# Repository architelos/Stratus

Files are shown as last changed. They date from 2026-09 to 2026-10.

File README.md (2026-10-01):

# Stratus

My take on an custom, open source yet practical drone stack.

## Jett (ESC)

<p align="center">
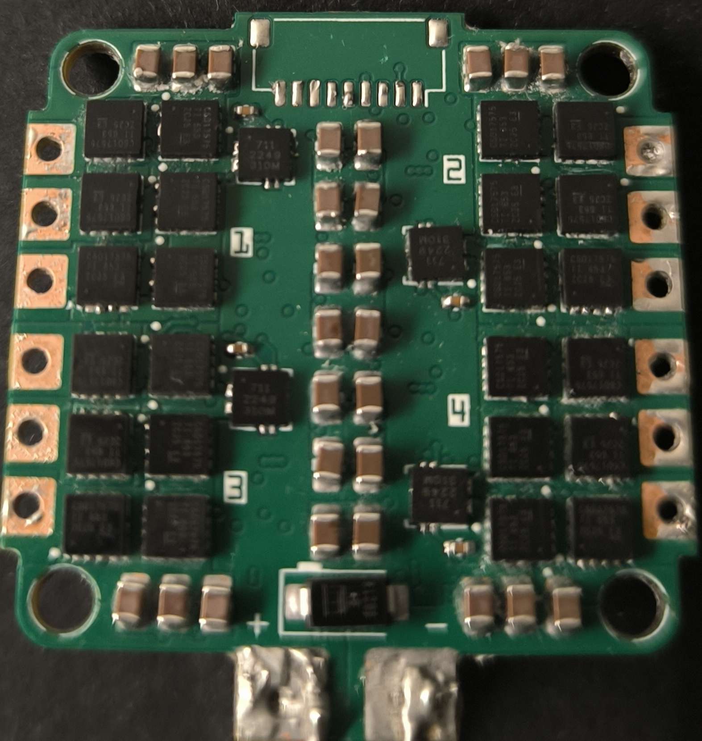
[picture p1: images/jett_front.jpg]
  
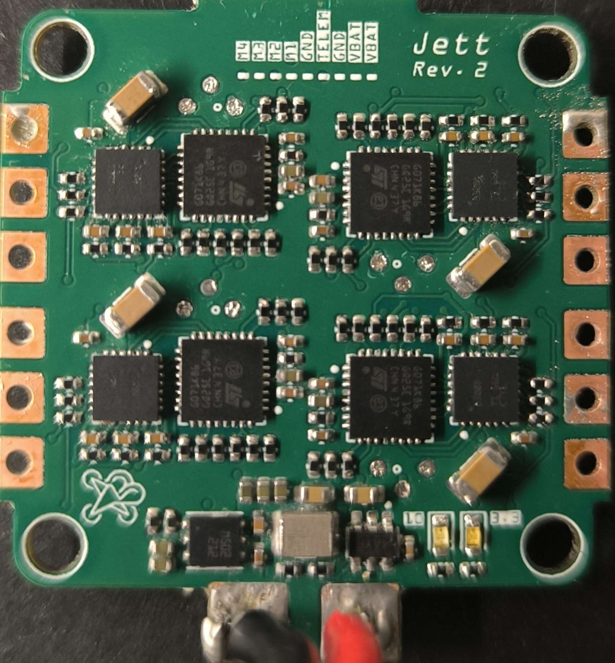
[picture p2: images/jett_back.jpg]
  
</p>

**Current revision:** 2\
**Status:** Testing

### Specs

| | |
| --- | --- |
| MCU | STM32G071K(B/8)U(3/6) |
| Gate driver | DRV8300DRGER |
| PWM | 48 kHz |
| Input | 2S to 4S LiPo |
| Continuous current | 25 A continuous, 30 A peaks |
| Current sensing | High side hall effect sensor |
| Throttle interface | DShot / ... (standard protocols) |
| Telemetry | Serial UART |
| Capacitor bank | 26 × 10 µF 0805 MLCC |
| PCB | 38 x 41.5 mm, 30.5 × 30.5 mm mounting |
| Copper | 2 oz outer, 0.5 oz inner |

### Description

Built from the ground up to understand what is happening inside an ESC, rather than treating it as a black box. Jett uses industry standard AM32, and has hardware designed around being able to inspect, modify, and learn from the system.

**Power tree:** `VBAT → 10V buck (driving FETs) → 3.3V low-noise LDO`

## Kite (FC)

<p align="center">
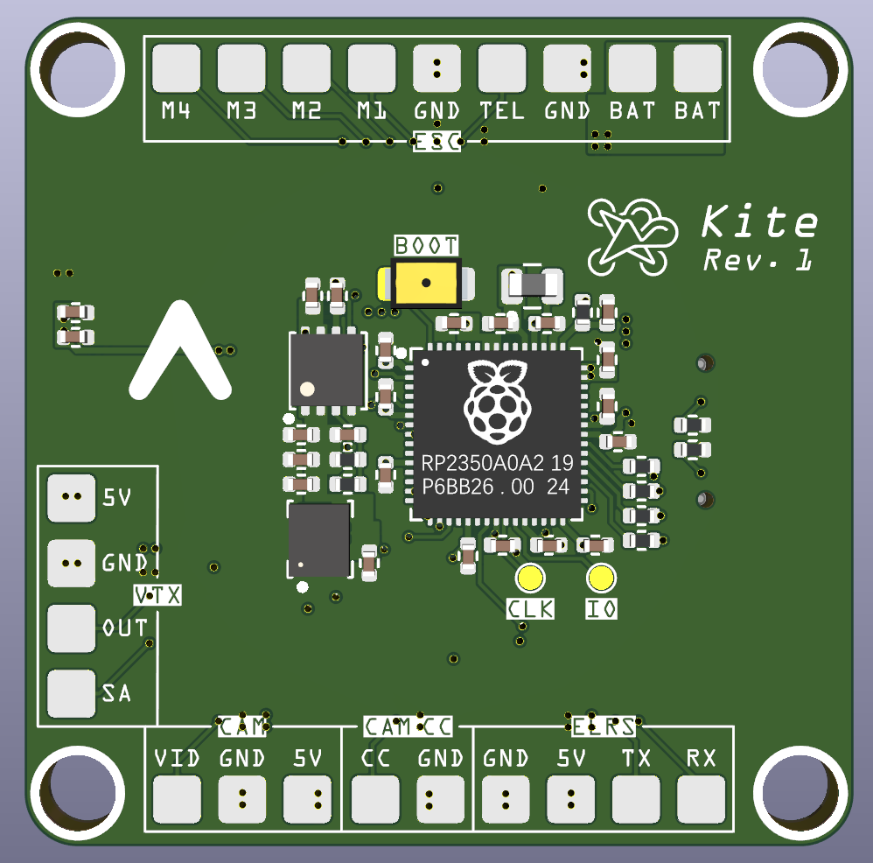
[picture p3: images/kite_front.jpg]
  
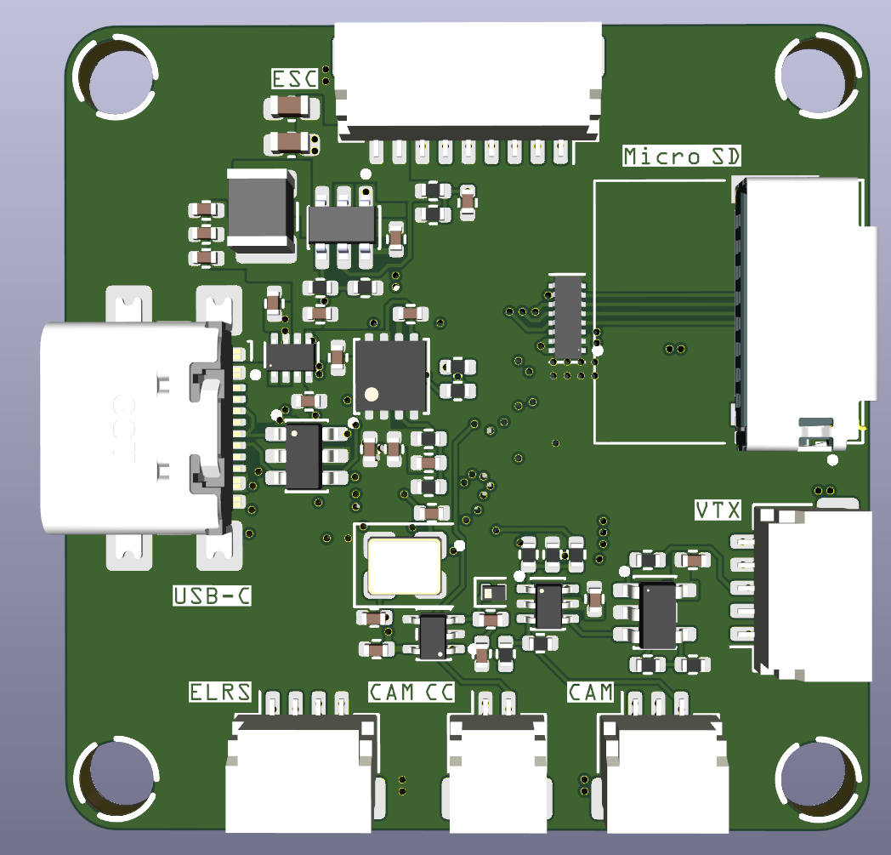
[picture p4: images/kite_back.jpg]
  
</p>

**Current revision:** 1\
**Status:** Waiting

### Specs

| | |
| --- | --- |
| MCU | RP2354A |
| IMU | LSM6DSK320X |
| Input | 2S to 4S LiPo |
| BECs | 5V → VTX + Camera ; 3V3 → MCU + IMU |
| Connectivity | USB-C / JST-SH |
| Storage | MicroSD |
| Firmware | Betaflight |
| PCB | 38 × 38 mm, 30.5 × 30.5 mm mounting |
| Copper | 1 oz outer, 0.5 oz inner |

The flight controller completes the Stratus stack, with the same focus on practical hardware and understanding the underlying system.

## License

CERN-OHL-2.0, see [LICENSE](LICENSE)

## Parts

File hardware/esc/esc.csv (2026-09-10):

Reference | Qty | Value | MFR | MPN | LCSC# | Footprint | Description | DNP | Exclude from Board | Exclude from BOM | Datasheet
C2,C6,C9,C10,C11,C15,C18,C19,C20,C24,C27,C28,C29,C33,C36,C37,C39,C70 | 18 | 0.1uF | TDK | CGA2B3X7R1V104KT0Y0F | C343047 | Stratus:C_0402 | 0402 0.1uF 35V
C3,C12,C21,C30,C40,C42,C65,C68,C69 | 9 | 4.7uF | Taiyo Yuden | TDK105CBJ475MV-F | C22385335 | Stratus:C_0402 | 0402 4.7uF 25V
C4,C5,C8,C13,C14,C17,C22,C23,C26,C31,C32,C35,C43 | 13 | 1uF | Murata | GRM155R6YA105KE11J | C3835721 | Stratus:C_0402 | 0402 1uF 35V
C7,C16,C25,C34 | 4 | 10uF | Samsung | CL31B106KLHNNNE | C16195875 | Capacitor_SMD:C_1206_3216Metric | 1206 10uF 35V
C44,C45,C46,C47,C48,C49,C50,C54,C55,C56,C57,C58,C59,C60,C61,C62,C64,C73,C74,C75,C76,C77,C78,C79,C80,C81 | 26 | 10uF | Murata | GRM21BR6YA106KE43L | C162422 | Capacitor_SMD:C_0805_2012Metric | 0805 10uF 35V
C66,C67 | 2 | 4.7uF | Samsung | CL10A475KL8NRNC | C307467 | Capacitor_SMD:C_0603_1608Metric | 0603 4.7uF 35V
D1,D2 | 2 | Green | Vishay | VLMTG1400-GS08 | C3000897 | LED_SMD:LED_0603_1608Metric | 0603 Green LED
D3 | 1 | SMAJ20A | Littelfuse | SMAJ20A | C148209 | Stratus:SMAJ20A | 32.4VC DO-214AC |  |  |  | https://www.littelfuse.com/media?itemid=75e32973-b177-4ee3-a0ff-cedaf1abdb93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
J1 | 1 | TO_FC | JST | SM09B-SRSS-TB(LF)(SN) | C160408 | Connector_JST:JST_SH_SM09B-SRSS-TB_1x09-1MP_P1.00mm_Horizontal | Horizontal JST-SH 1x9
J4,J7,J10,J13 | 4 | PHASE_A |  |  |  | Stratus:Phase_Pad_3x3_D1.5 | Motor output pad
J5,J8,J11,J14 | 4 | PHASE_B |  |  |  | Stratus:Phase_Pad_3x3_D1.5 | Motor output pad
J6,J9,J12,J15 | 4 | PHASE_C |  |  |  | Stratus:Phase_Pad_3x3_D1.5 | Motor output pad
L1 | 1 | 4.7uH | TDK | BCL322520RT-4R7M-D | C3224690 | Inductor_SMD:L_1210_3225Metric | 1210 4.7uH 2.5A Isat
Q1,Q2,Q3,Q4,Q5,Q6,Q7,Q8,Q9,Q10,Q11,Q12,Q13,Q14,Q15,Q16,Q17,Q18,Q19,Q20,Q21,Q22,Q23,Q24 | 24 | CSD17575Q3 | TI | CSD17575Q3 | C529277 | Stratus:CSD17575Q3 | N-Channel MOSFET 30V 60A 2.8W |  |  |  | https://www.ti.com/lit/ds/symlink/csd17575q3.pdf
R1,R3 | 2 | 1k | Yageo | RC0402FR-071KL | C106235 | Stratus:R_0402 | 0402 1k
R5,R13,R14,R15,R22,R30,R31,R32,R39,R47,R48,R49,R56,R64,R65,R66,R76,R77 | 18 | 10k | Yageo | RC0402FR-0710KL | C60490 | Stratus:R_0402 | 0402 10k
R6,R7,R8,R9,R11,R12,R23,R24,R25,R26,R28,R29,R40,R41,R42,R43,R45,R46,R57,R58,R59,R60,R62,R63 | 24 | 56k | Yageo | RC0402FR-0756KL | C114756 | Stratus:R_0402 | 0402 56k
R16,R17,R18,R19,R20,R21,R33,R34,R35,R36,R37,R38,R50,R51,R52,R53,R54,R55,R67,R68,R69,R70,R71,R72 | 24 | 27R | Yageo | RC0402FR-0727RL | C138021 | Stratus:R_0402 | 0402 27R
R74 | 1 | 18k | Yageo | RC0402FR-0718KL | C138044 | Stratus:R_0402 | 0402 18k
R75 | 1 | 160k | Yageo | RC0402FR-07160KL | C273334 | Stratus:R_0402 | 0402 160k
TP1,TP5,TP9,TP13 | 4 | DBG_nRST |  |  |  | Stratus:Debug_Pad_D1 | 1x1mm pad for flashing
U1,U4,U7,U10 | 4 | DRV8300DRGER | TI | DRV8300DRGER | C3655801 | Stratus:DRV8300DRGER | https://www.lcsc.com/datasheet/C3655801.pdf |  |  |  | https://www.ti.com/lit/gpn/drv8300
U2,U5,U8,U11 | 4 | STM32G071K8U6 | ST | STM32G071K8U6 | C724237 | Stratus:STM32G071K8U6 | https://www.lcsc.com/datasheet/C724237.pdf |  |  |  | https://www.st.com/resource/en/datasheet/stm32g071c8.pdf
U13 | 1 | LMR51420YFDDCR | TI | LMR51420YFDDCR | C7296200 | Stratus:LMR51420YFDDCR | 4.5-V to 36-V, 2-A, Synchronous Buck Converter |  |  |  | ti.com/lit/ds/symlink/lmr51420.pdf
U14 | 1 | LDL212PUR | ST | LDL212PUR | C2969849 | Stratus:LDLPUR212 | 1.18V~17.3V Positive Adjustable DFN-6(3x3) |  |  |  | https://www.lcsc.com/datasheet/C2969849.pdf
U15,U16,U17,U18 | 4 | ACS711xEXLT-31AB | Allegro | ACS711KEXLT-31AB-T | C146412 | Stratus:ACS711KEXLT-31AB-T | ±31A Bidirectional, Hall-Effect Current Sensor, +3.3V supply, 45mV/A, QFN-12 |  |  |  | http://www.allegromicro.com/~/Media/Files/Datasheets/ACS711-Datasheet.ashx

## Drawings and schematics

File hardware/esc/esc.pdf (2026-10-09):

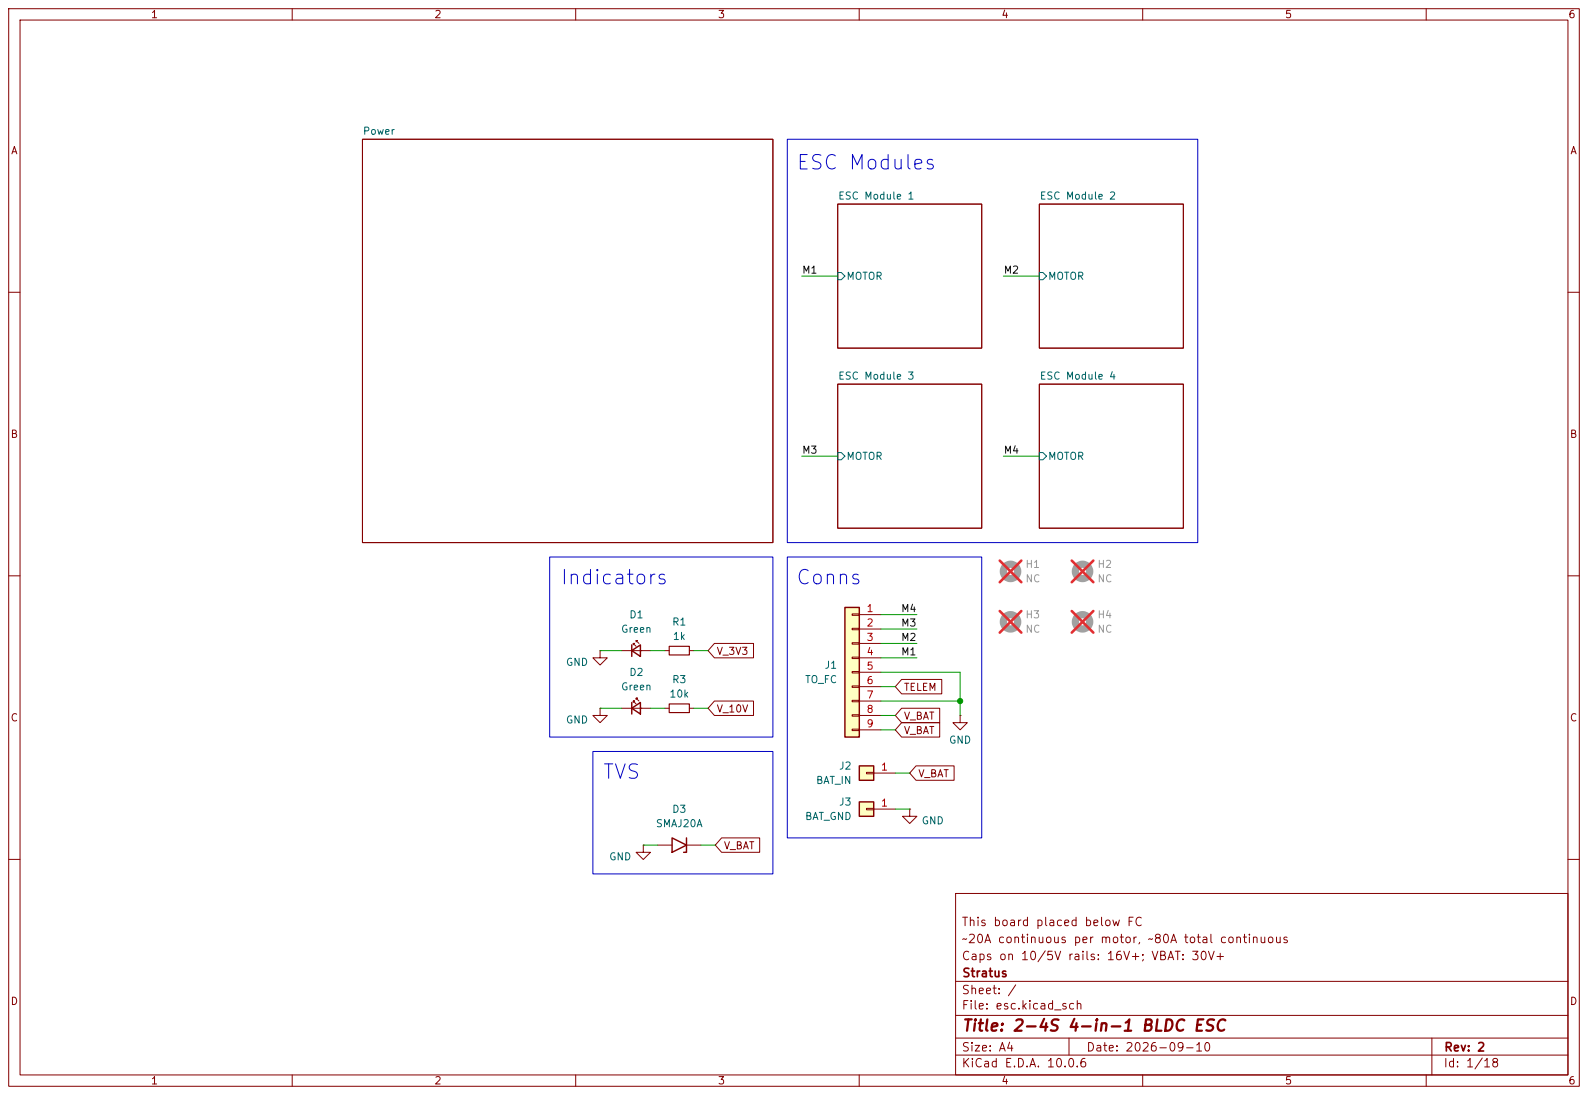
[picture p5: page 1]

This board placed below FC
~20A continuous per motor, ~80A total continuous
Caps on 10/5V rails: 16V+; VBAT: 30V+
Stratus
Sheet: /
File: esc.kicad_sch
Title: 2-4S 4-in-1 BLDC ESC

Size: A4 | Rev: 2
KiCad E.D.A. 10.0.6 | Id: 1/18

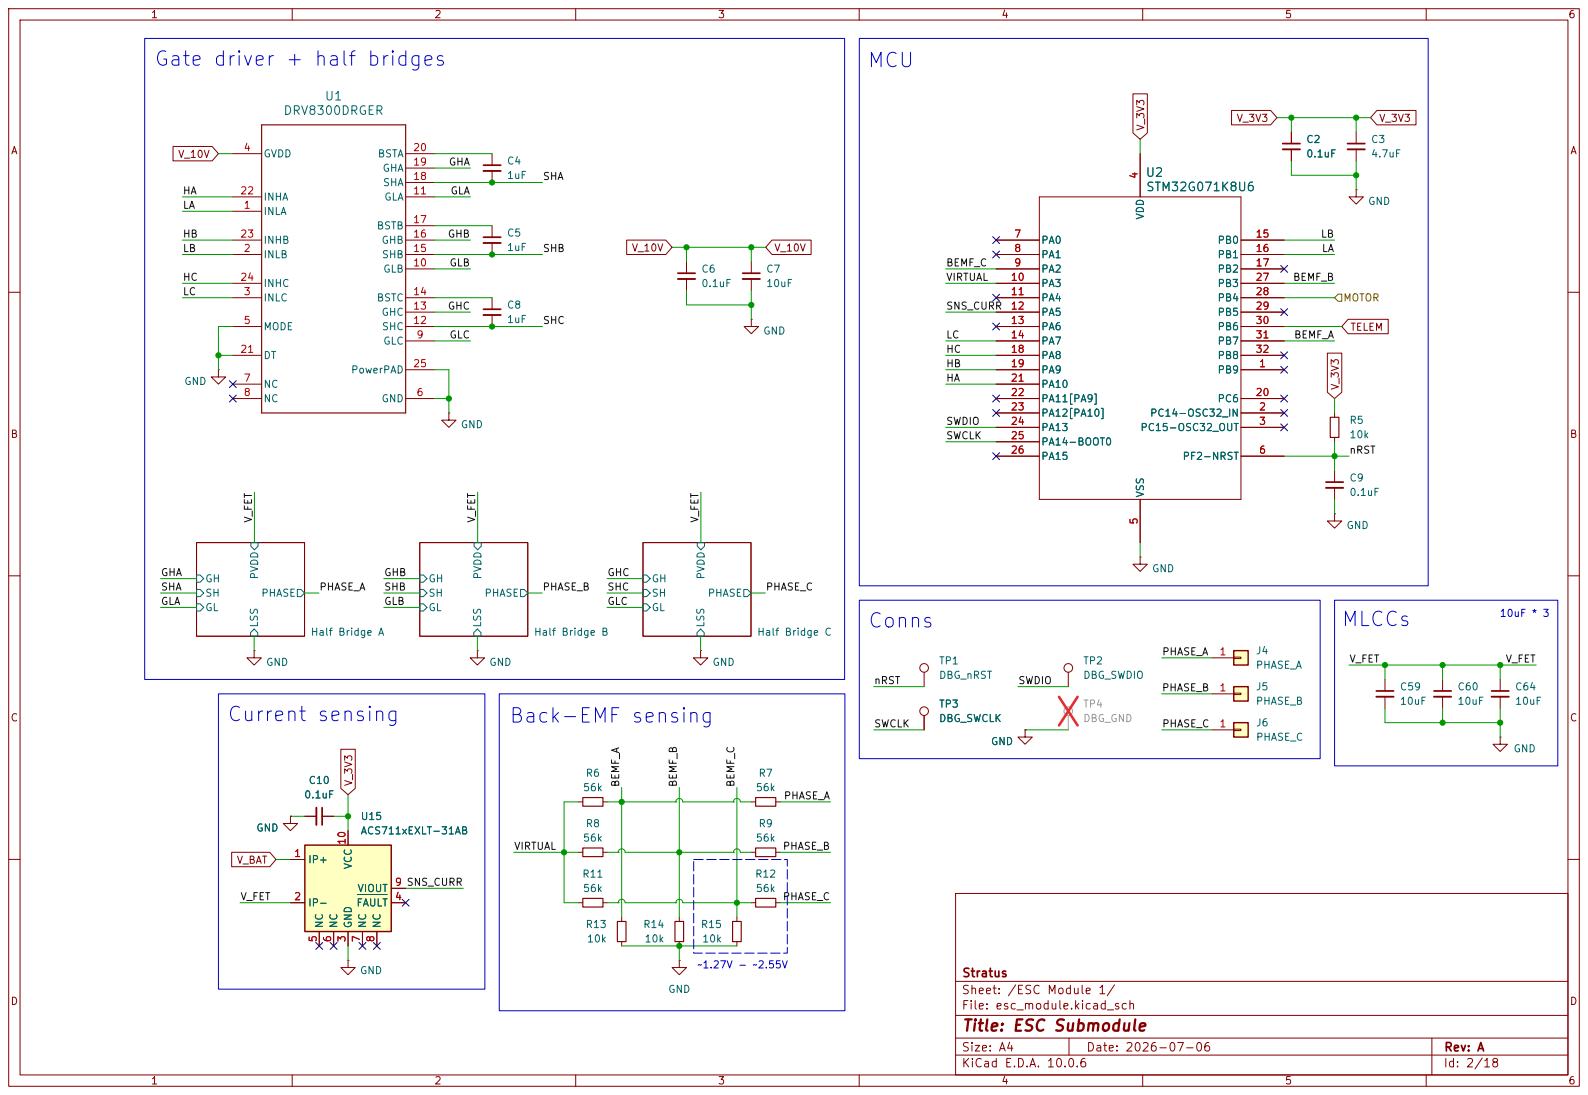
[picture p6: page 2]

~1.27V - ~2.55V Gate driver + half bridges

Stratus LSS PVDD PHASE GH

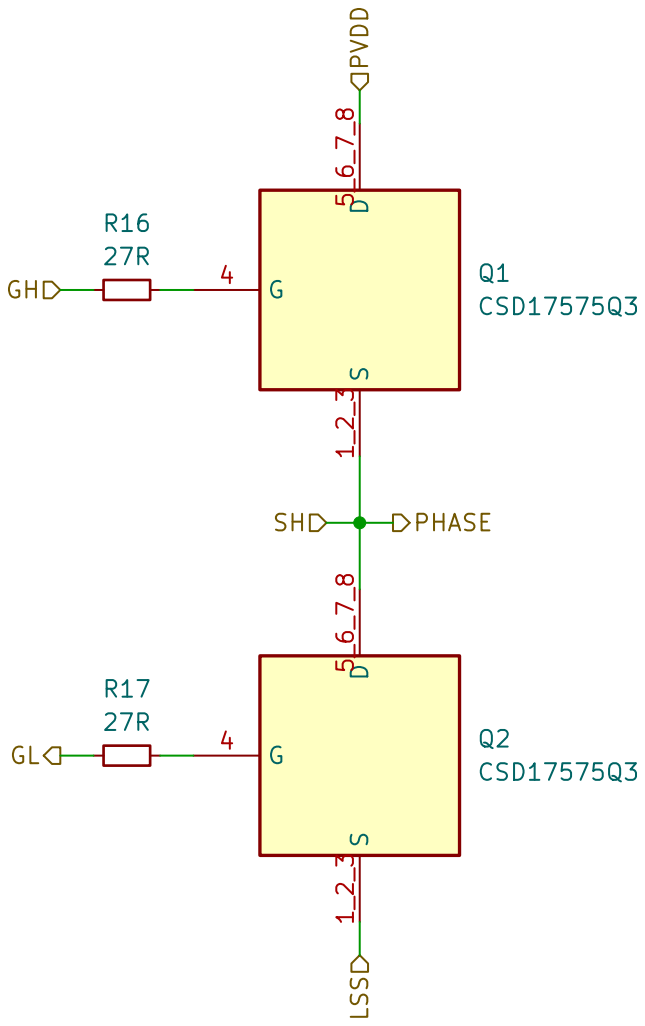
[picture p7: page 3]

Sheet: /ESC Module 1/Half Bridge A/
File: half_bridge.kicad_sch
Title: MOSFET half bridge

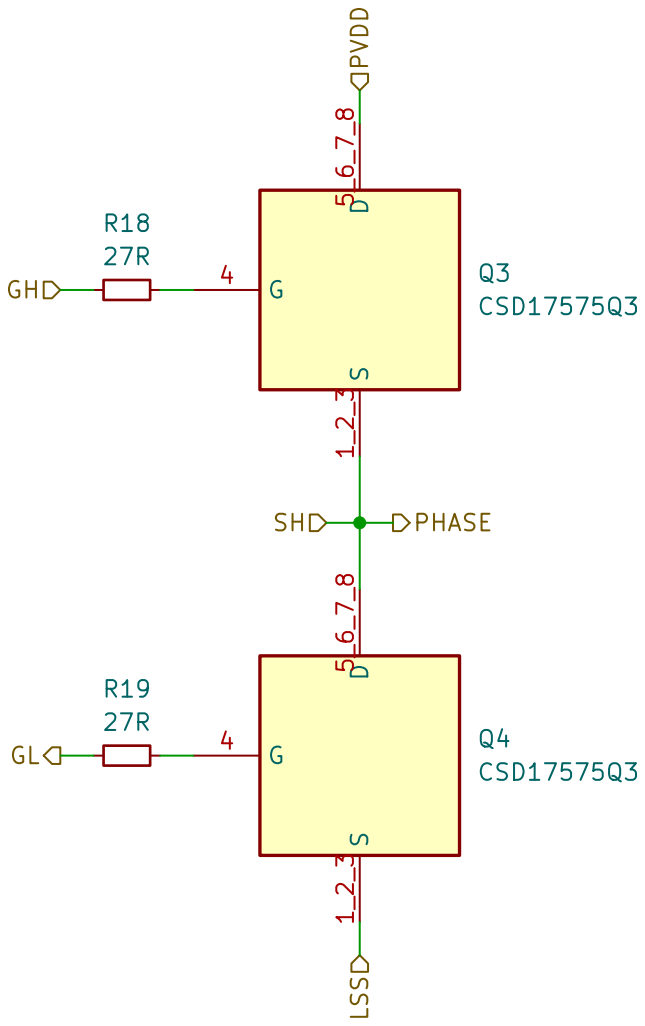
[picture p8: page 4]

Sheet: /ESC Module 1/Half Bridge B/
File: half_bridge.kicad_sch
Title: MOSFET half bridge

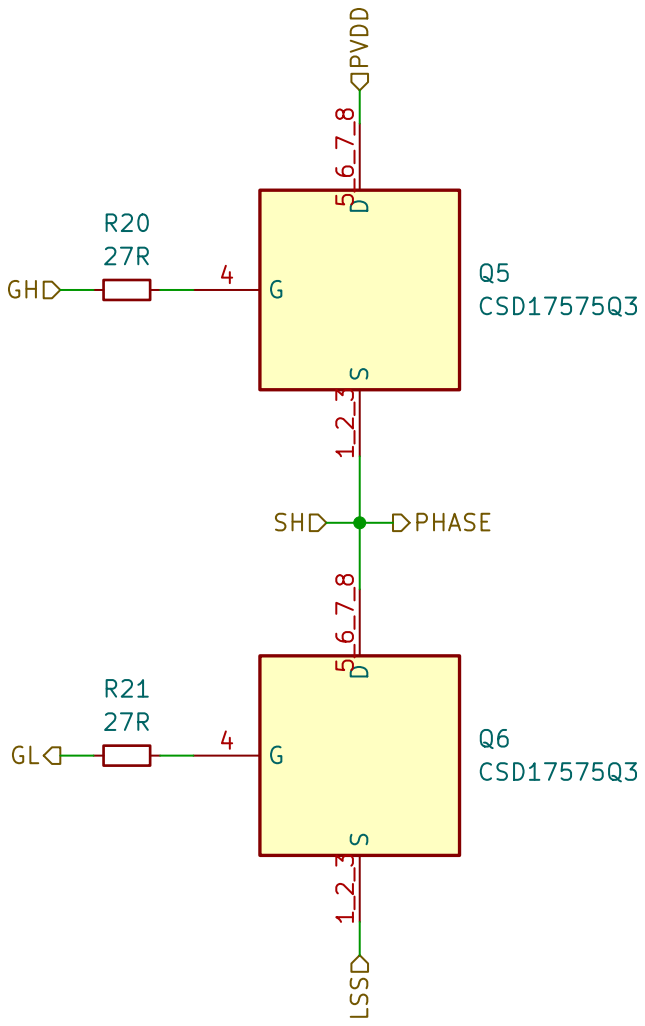
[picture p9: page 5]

Sheet: /ESC Module 1/Half Bridge C/
File: half_bridge.kicad_sch
Title: MOSFET half bridge

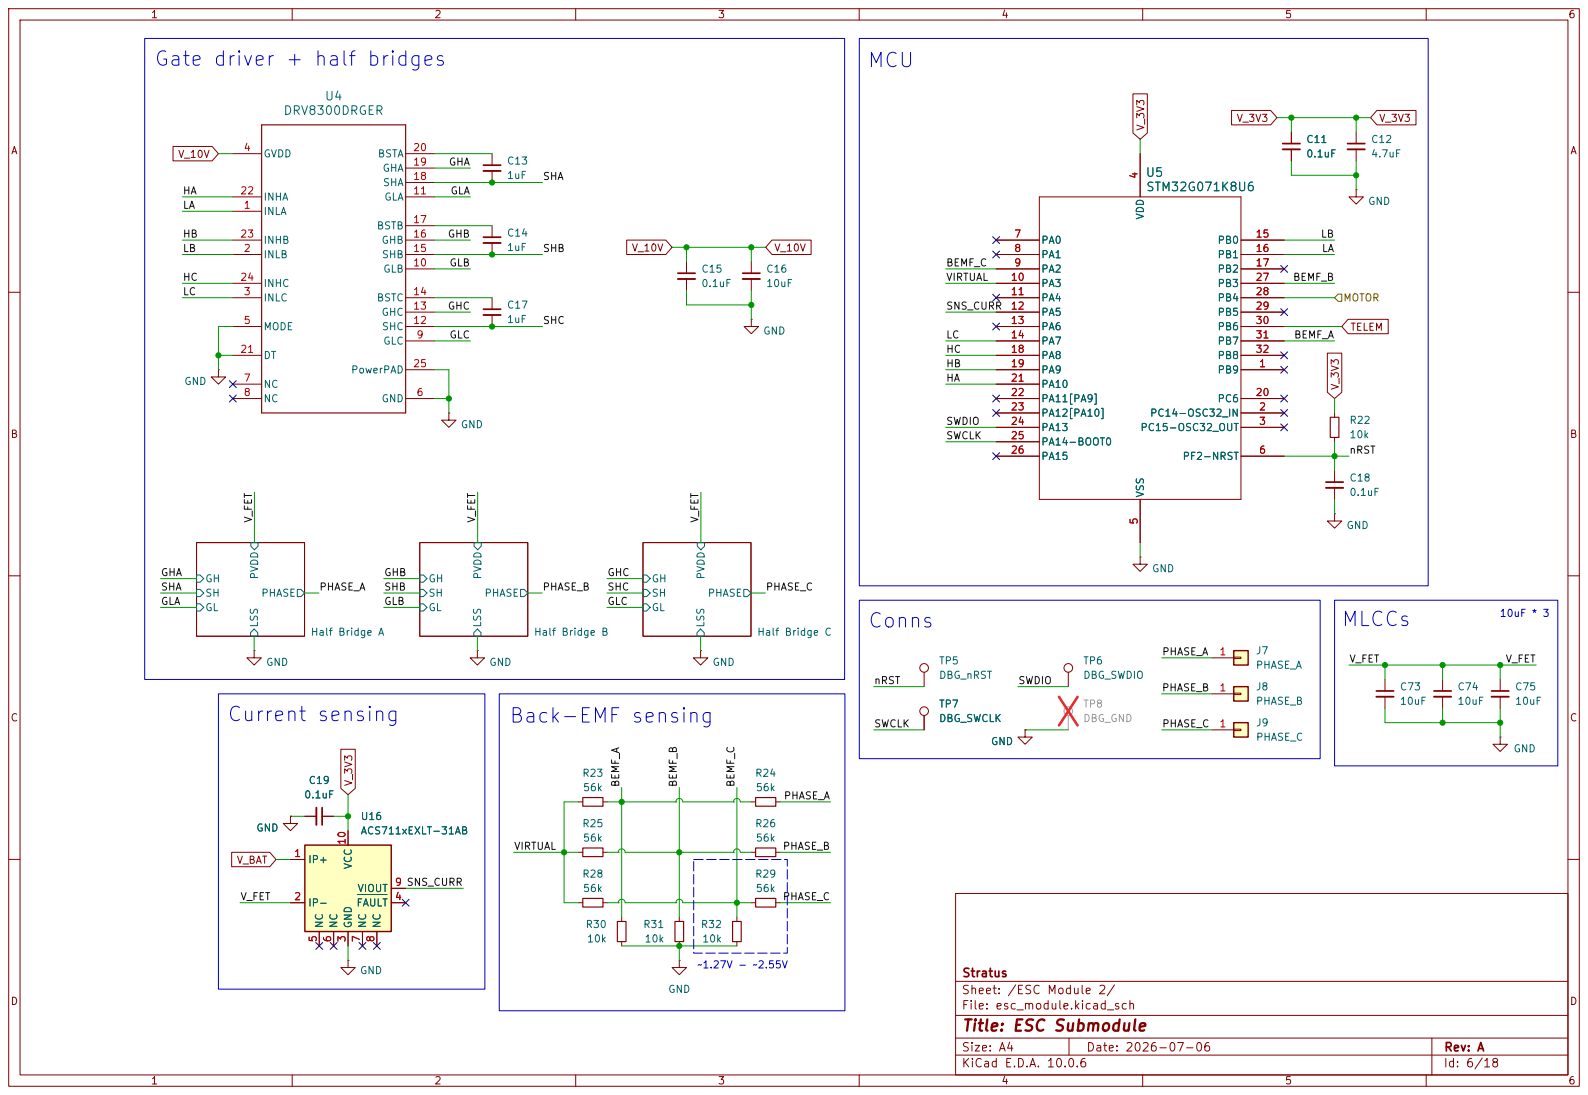
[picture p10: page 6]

10uF * 3 Gate driver + half bridges

Stratus LSS PVDD PHASE GH

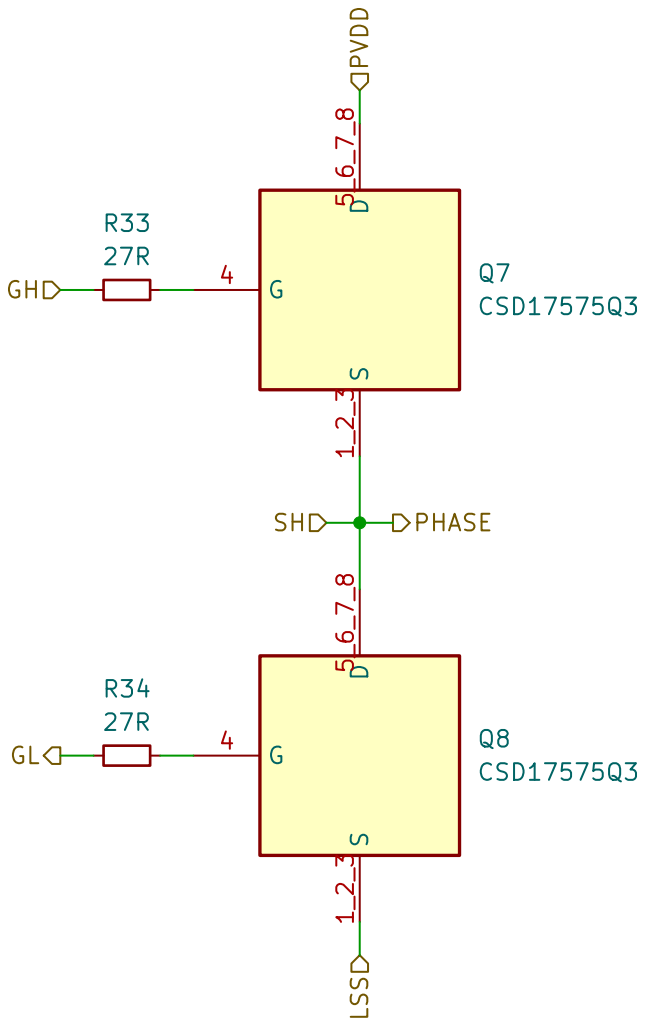
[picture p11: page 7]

Sheet: /ESC Module 2/Half Bridge B/
File: half_bridge.kicad_sch
Title: MOSFET half bridge

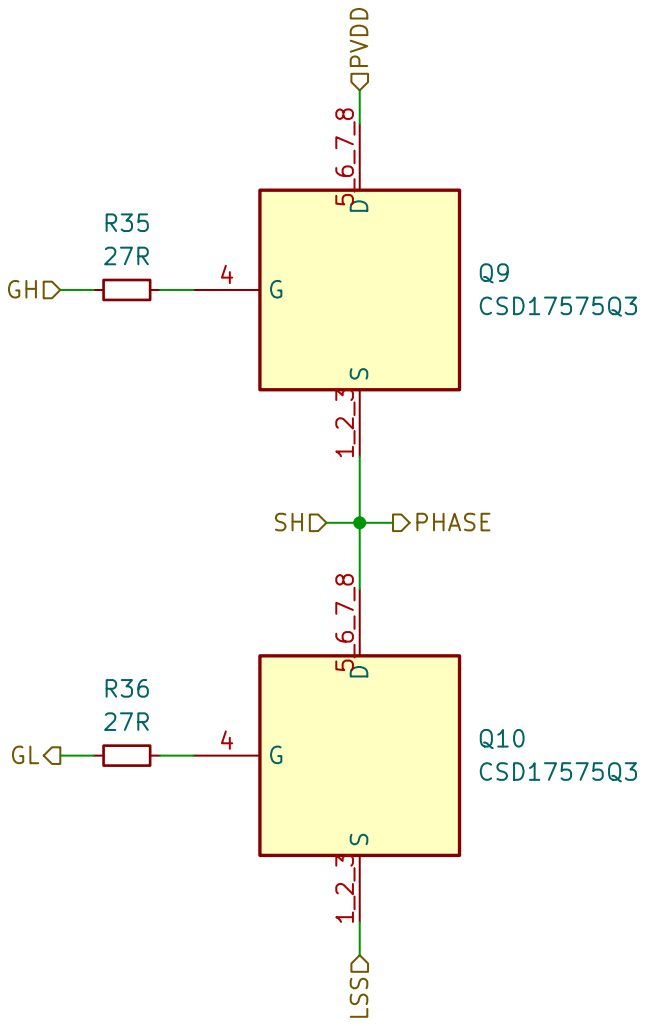
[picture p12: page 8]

Sheet: /ESC Module 2/Half Bridge C/
File: half_bridge.kicad_sch
Title: MOSFET half bridge

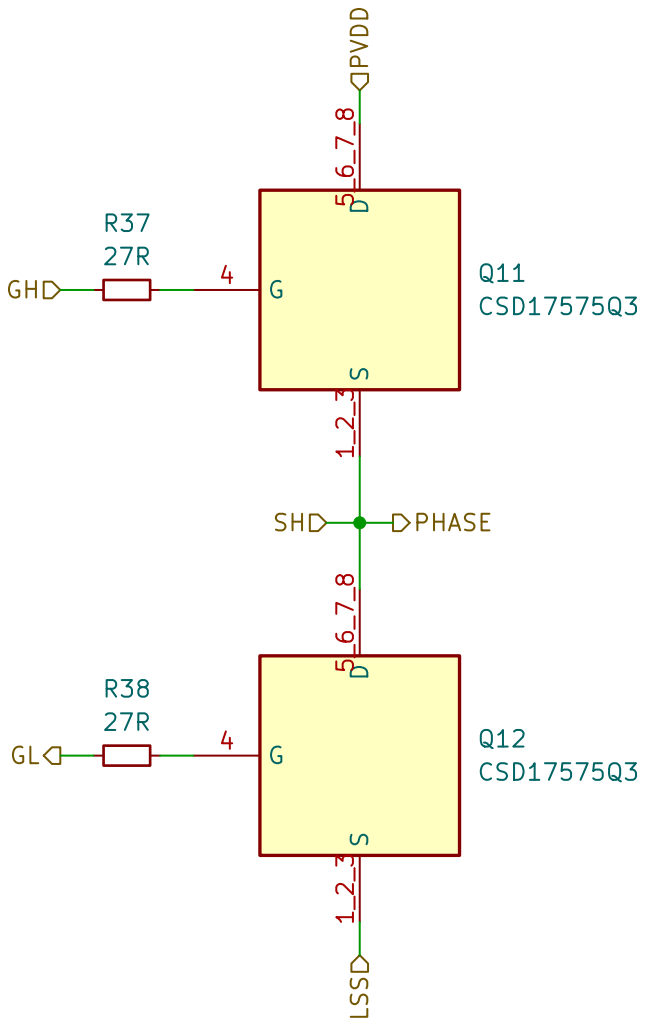
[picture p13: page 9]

Sheet: /ESC Module 2/Half Bridge A/
File: half_bridge.kicad_sch
Title: MOSFET half bridge

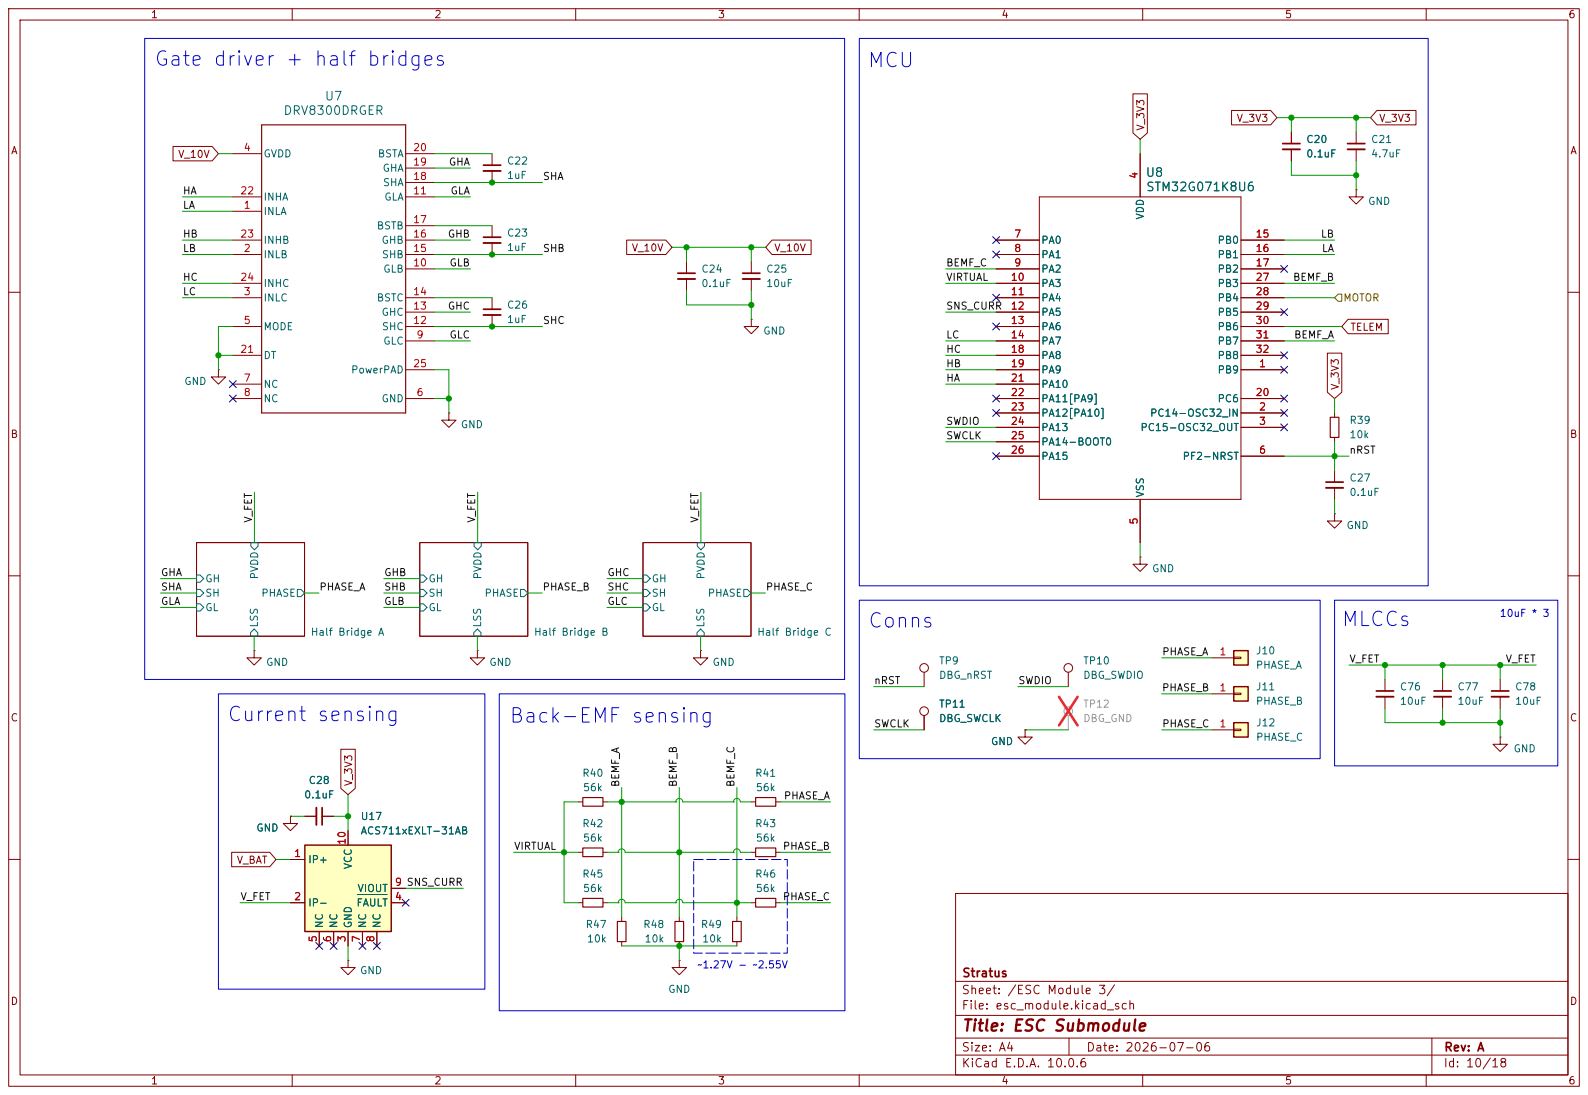
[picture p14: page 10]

~1.27V - ~2.55V Gate driver + half bridges

Stratus LSS PVDD PHASE GH

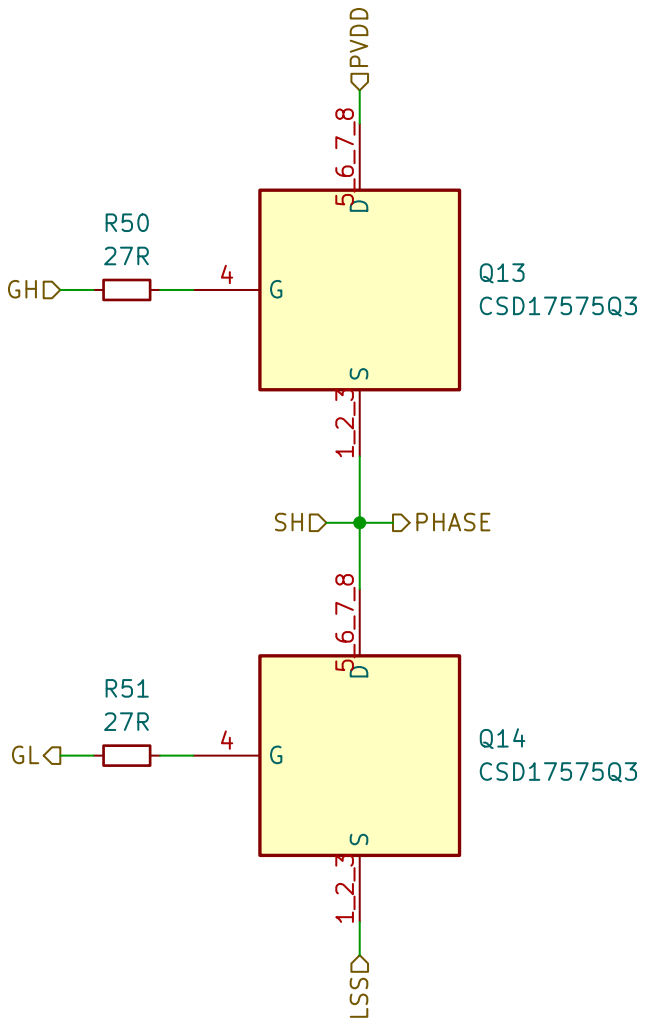
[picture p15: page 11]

Sheet: /ESC Module 3/Half Bridge B/
File: half_bridge.kicad_sch
Title: MOSFET half bridge

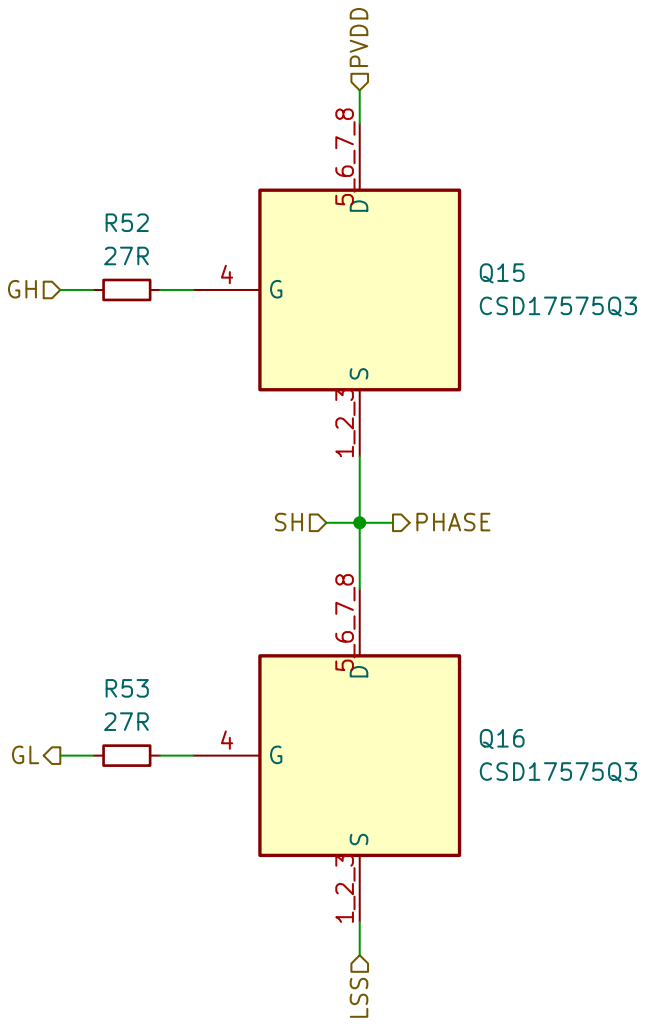
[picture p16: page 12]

Sheet: /ESC Module 3/Half Bridge C/
File: half_bridge.kicad_sch
Title: MOSFET half bridge


Sheet: /ESC Module 3/Half Bridge A/
File: half_bridge.kicad_sch
Title: MOSFET half bridge


10uF * 3 Gate driver + half bridges

Stratus LSS PVDD PHASE GH


Sheet: /ESC Module 4/Half Bridge B/
File: half_bridge.kicad_sch
Title: MOSFET half bridge


Sheet: /ESC Module 4/Half Bridge C/
File: half_bridge.kicad_sch
Title: MOSFET half bridge


Sheet: /ESC Module 4/Half Bridge A/
File: half_bridge.kicad_sch
Title: MOSFET half bridge


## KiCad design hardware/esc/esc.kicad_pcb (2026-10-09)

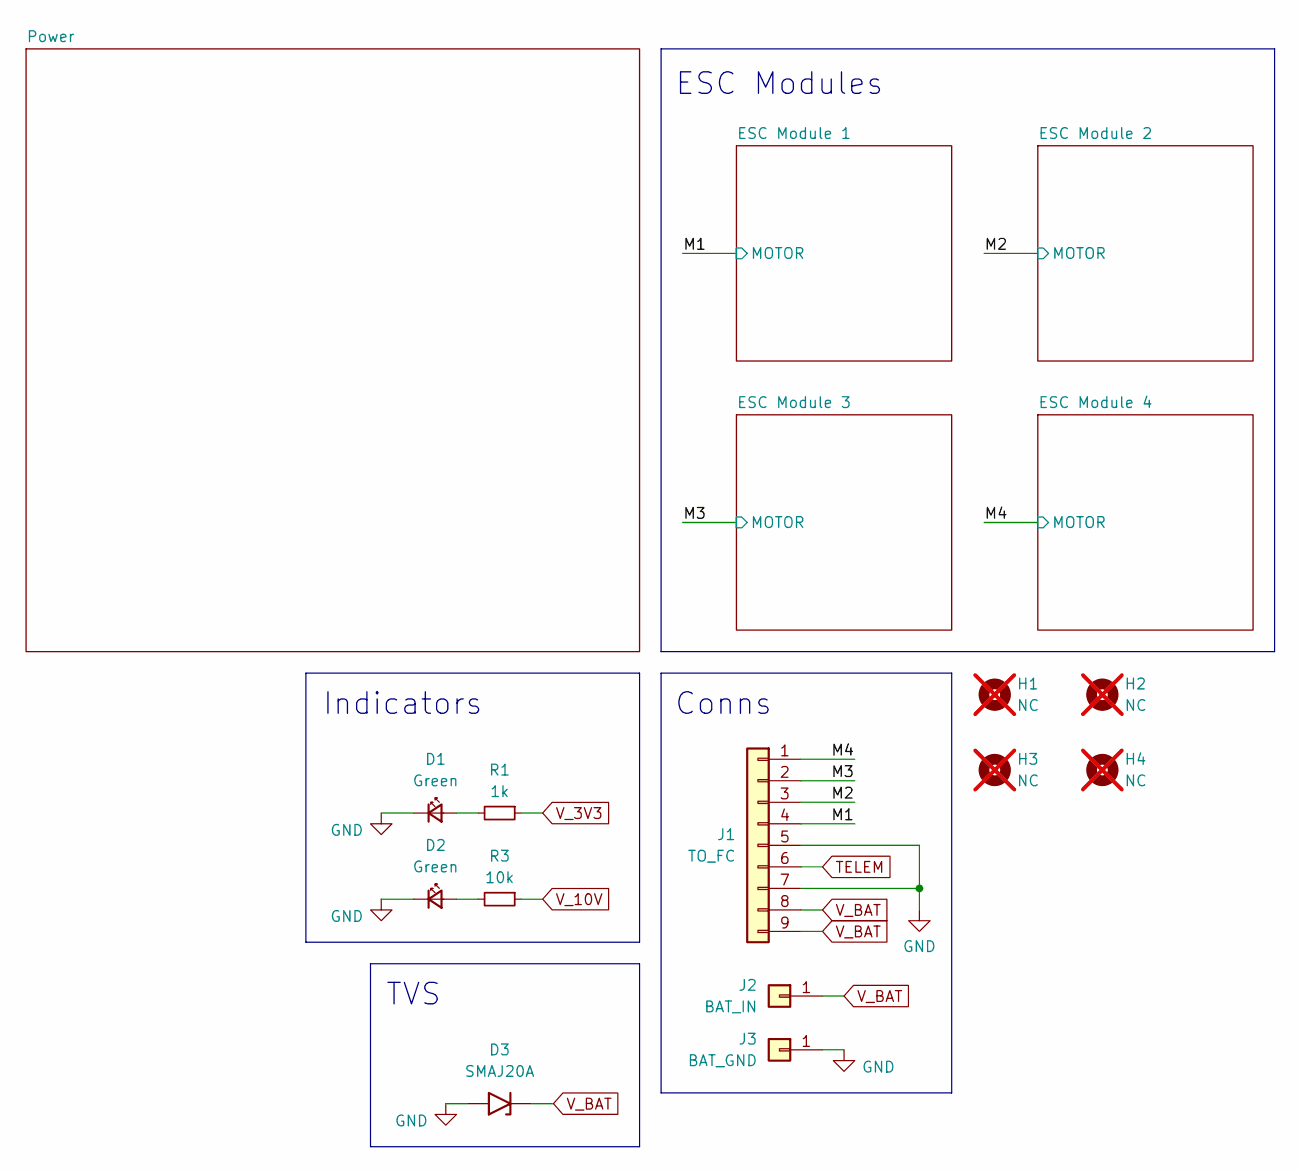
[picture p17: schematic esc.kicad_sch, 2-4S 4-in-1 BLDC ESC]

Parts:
D1, D2: Green; LED_0603_1608Metric; MPN VLMTG1400-GS08; LCSC# C3000897
D3: SMAJ20A; MPN SMAJ20A; LCSC# C148209
H1, H2, H3, H4: NC; Mount_M3_K0.5; not fitted
J1: TO_FC; JST_SH_1x9_ESC; MPN SM09B-SRSS-TB(LF)(SN); LCSC# C160408
J2: BAT_IN; Input_5x5_D2.5_R
J3: BAT_GND; Input_5x5_D2.5_L
R1: 1k; R_0402; MPN RC0402FR-071KL; LCSC# C106235
R3: 10k; R_0402; MPN RC0402FR-071KL; LCSC# C106235

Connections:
/M1: J1.4; also elsewhere on the board
/M2: J1.3; also elsewhere on the board
/M3: J1.2; also elsewhere on the board
/M4: J1.1; also elsewhere on the board
GND: D1.1 (K), D2.1 (K), D3.2 (A2), J1.5, J1.7, J3.1 (Pin_1_1); also elsewhere on the board
unnamed: D1.2 (A), R1.2
unnamed: D2.2 (A), R3.2
TELEM: J1.6; also elsewhere on the board
V_3V3: R1.1; also elsewhere on the board
V_10V: R3.1; also elsewhere on the board
V_BAT: D3.1 (A1), J1.8, J1.9, J2.1 (Pin_1_1); also elsewhere on the board

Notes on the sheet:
Indicators
ESC Modules
TVS
Conns

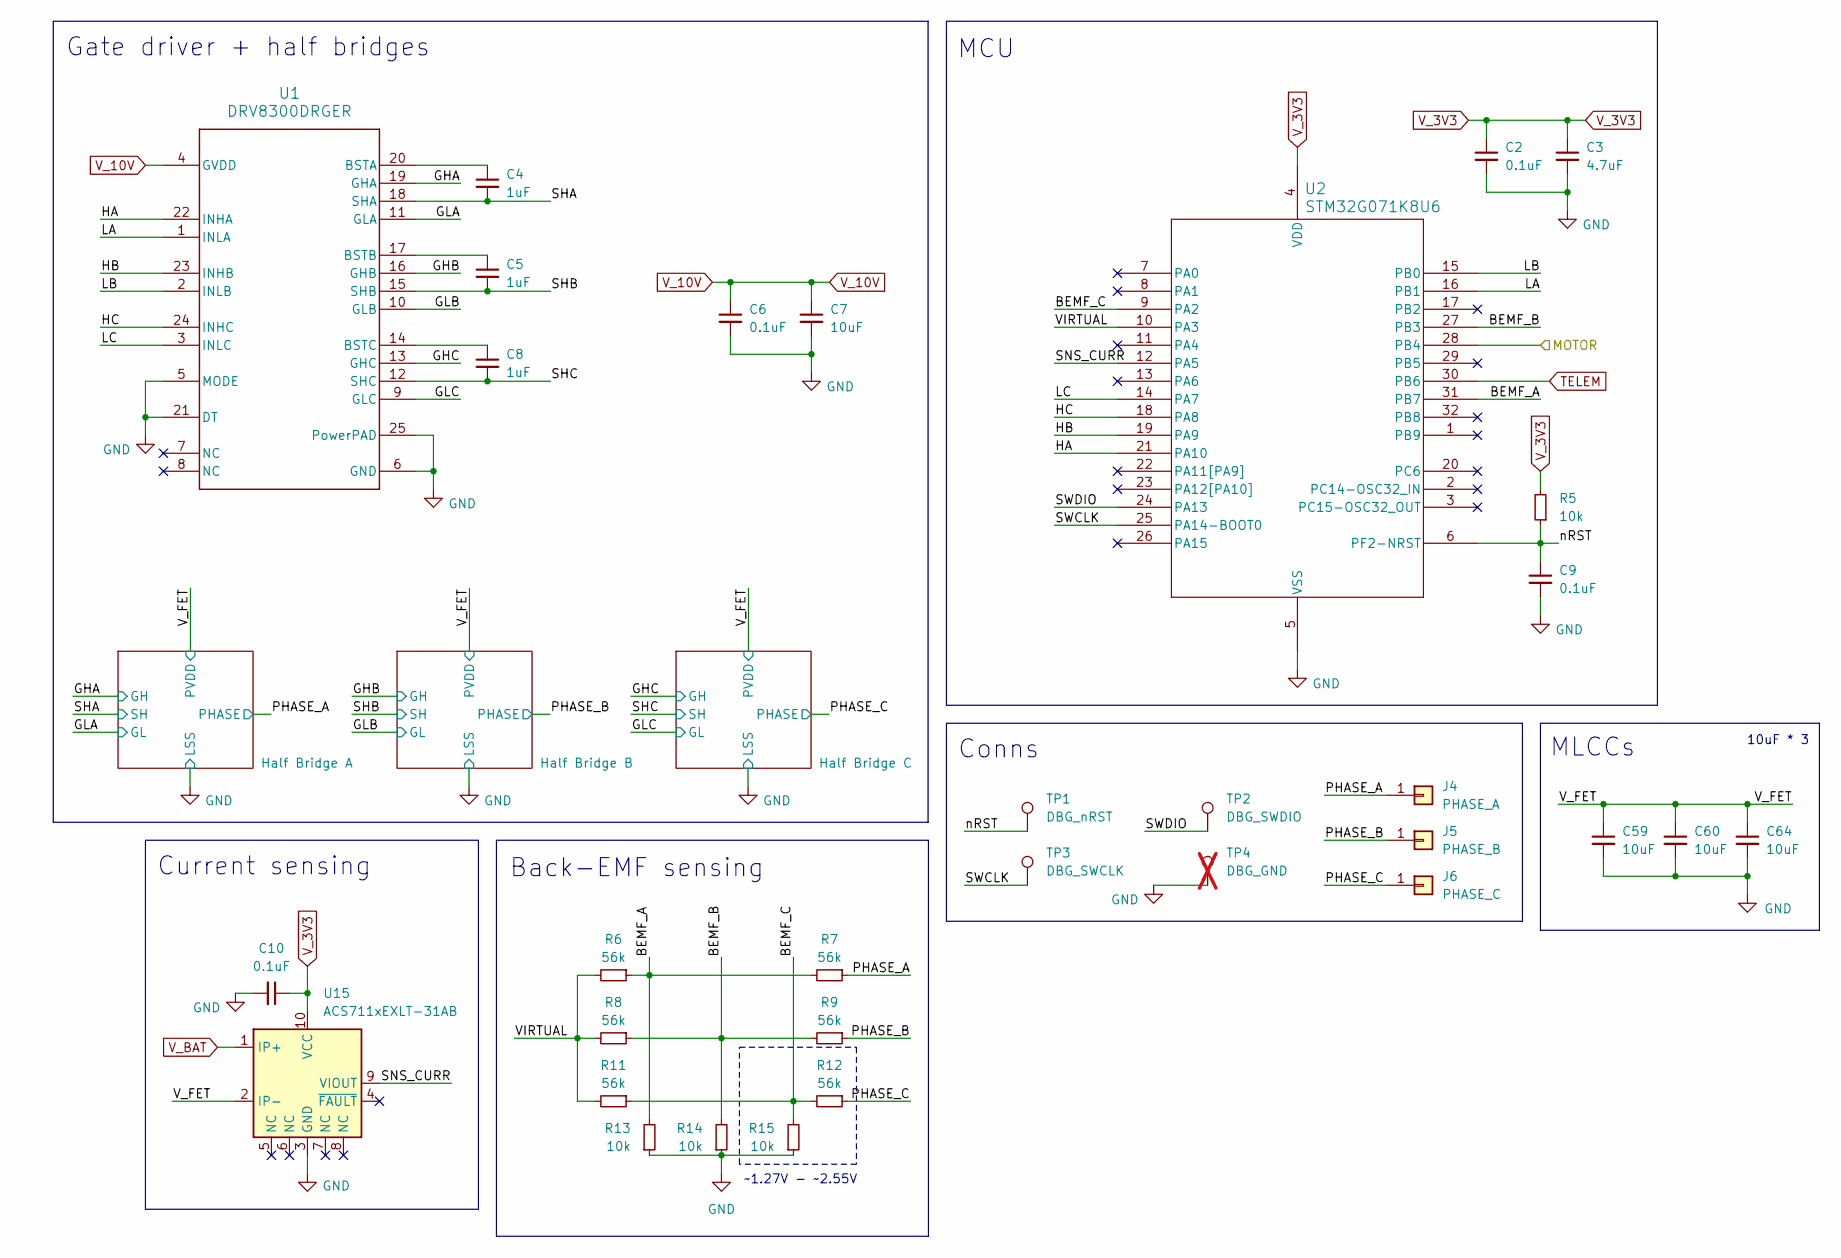
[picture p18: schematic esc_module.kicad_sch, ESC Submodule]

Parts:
C2, C6, C9, C10: 0.1uF; C_0402; MPN CGA2B3X7R1V104KT0Y0F; LCSC# C343047
C3: 4.7uF; C_0402; MPN TDK105CBJ475MV-F; LCSC# C22385335
C4, C5, C8: 1uF; C_0402; MPN GRM155R6YA105KE11J; LCSC# C3835721
C7: 10uF; C_1206_3216Metric; MPN CL31B106KLHNNNE; LCSC# C16195875
C59, C60, C64: 10uF; C_0805_2012Metric; MPN GRM21BR6YA106KE43L; LCSC# C162422
J4: PHASE_A; Phase_Pad_3x3_D1.5
J5: PHASE_B; Phase_Pad_3x3_D1.5
J6: PHASE_C; Phase_Pad_3x3_D1.5
R5, R13, R14, R15: 10k; R_0402; MPN RC0402FR-0710KL; LCSC# C60490
R6, R7, R8, R9, R11, R12: 56k; R_0402; MPN RC0402FR-0756KL; LCSC# C114756
TP1: DBG_nRST; Debug_Pad_D1
TP2: DBG_SWDIO; Debug_Pad_D1
TP3: DBG_SWCLK; Debug_Pad_D1
TP4: DBG_GND; Debug_Pad_D1; not fitted
U1: DRV8300DRGER; MPN DRV8300DRGER; LCSC# C3655801
U2: STM32G071K8U6; MPN STM32G071K8U6; LCSC# C724237
U15: ACS711xEXLT-31AB; ACS711KEXLT-31AB-T; MPN ACS711KEXLT-31AB-T; LCSC# C146412

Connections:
/ESC Module 1/BEMF_A: R6.1, R7.2, R13.2, U2.31 (PB7)
/ESC Module 1/BEMF_B: R8.1, R9.2, R14.2, U2.27 (PB3)
/ESC Module 1/BEMF_C: R11.1, R12.2, R15.2, U2.9 (PA2)
/ESC Module 1/GHA: U1.19 (GHA); also elsewhere on the board
/ESC Module 1/GHB: U1.16 (GHB); also elsewhere on the board
/ESC Module 1/GHC: U1.13 (GHC); also elsewhere on the board
/ESC Module 1/GLA: U1.11 (GLA); also elsewhere on the board
/ESC Module 1/GLB: U1.10 (GLB); also elsewhere on the board
/ESC Module 1/GLC: U1.9 (GLC); also elsewhere on the board
/ESC Module 1/HA: U1.22 (INHA), U2.21 (PA10)
/ESC Module 1/HB: U1.23 (INHB), U2.19 (PA9)
/ESC Module 1/HC: U1.24 (INHC), U2.18 (PA8)
/ESC Module 1/LA: U1.1 (INLA), U2.16 (PB1)
/ESC Module 1/LB: U1.2 (INLB), U2.15 (PB0)
/ESC Module 1/LC: U1.3 (INLC), U2.14 (PA7)
/ESC Module 1/PHASE_A: C4.2, J4.1 (Pin_1_1), R7.1, U1.18 (SHA); also elsewhere on the board
/ESC Module 1/PHASE_B: C5.2, J5.1 (Pin_1_1), R9.1, U1.15 (SHB); also elsewhere on the board
/ESC Module 1/PHASE_C: C8.2, J6.1 (Pin_1_1), R12.1, U1.12 (SHC); also elsewhere on the board
/ESC Module 1/SNS_CURR: U2.12 (PA5), U15.9 (VIOUT)
/ESC Module 1/SWCLK: TP3.1 (1_1), U2.25 (PA14-BOOT0)
/ESC Module 1/SWDIO: TP2.1 (1_1), U2.24 (PA13)
/ESC Module 1/VIRTUAL: R6.2, R8.2, R11.2, U2.10 (PA3)
/ESC Module 1/V_FET: C59.1, C60.1, C64.1, U15.2 (IP-); also elsewhere on the board
/ESC Module 1/nRST: C9.1, R5.1, TP1.1 (1_1), U2.6 (PF2-NRST)
/M1: U2.28 (PB4); also elsewhere on the board
GND: C2.2, C3.2, C6.2, C7.2, C9.2, C10.2, C59.2, C60.2, C64.2, R13.1, R14.1, R15.1, TP4.1, U1.5 (MODE), U1.6 (GND), U1.21 (DT), U1.25 (PowerPAD), U2.5 (VSS), U15.3 (GND); also elsewhere on the board
unnamed: C4.1, U1.20 (BSTA)
unnamed: C5.1, U1.17 (BSTB)
unnamed: C8.1, U1.14 (BSTC)
TELEM: U2.30 (PB6); also elsewhere on the board
V_3V3: C2.1, C3.1, C10.1, R5.2, U2.4 (VDD), U15.10 (VCC); also elsewhere on the board
V_10V: C6.1, C7.1, U1.4 (GVDD); also elsewhere on the board
V_BAT: U15.1 (IP+); also elsewhere on the board

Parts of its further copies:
C11, C15, C18, C19, C20, C24, C27, C28, C29, C33, C36, C37: 0.1uF; C_0402; MPN CGA2B3X7R1V104KT0Y0F; LCSC# C343047
C12, C21, C30: 4.7uF; C_0402; MPN TDK105CBJ475MV-F; LCSC# C22385335
C13, C14, C17, C22, C23, C26, C31, C32, C35: 1uF; C_0402; MPN GRM155R6YA105KE11J; LCSC# C3835721
C16, C25, C34: 10uF; C_1206_3216Metric; MPN CL31B106KLHNNNE; LCSC# C16195875
C73, C74, C75, C76, C77, C78, C79, C80, C81: 10uF; C_0805_2012Metric; MPN GRM21BR6YA106KE43L; LCSC# C162422
J7, J10, J13: PHASE_A; Phase_Pad_3x3_D1.5
J8, J11, J14: PHASE_B; Phase_Pad_3x3_D1.5
J9, J12, J15: PHASE_C; Phase_Pad_3x3_D1.5
R22, R30, R31, R32, R39, R47, R48, R49, R56, R64, R65, R66: 10k; R_0402; MPN RC0402FR-0710KL; LCSC# C60490
R23, R24, R25, R26, R28, R29, R40, R41, R42, R43, R45, R46, R57, R58, R59, R60, R62, R63: 56k; R_0402; MPN RC0402FR-0756KL; LCSC# C114756
TP5, TP9, TP13: DBG_nRST; Debug_Pad_D1
TP6, TP10, TP14: DBG_SWDIO; Debug_Pad_D1
TP7, TP11, TP15: DBG_SWCLK; Debug_Pad_D1
U4, U7, U10: DRV8300DRGER; MPN DRV8300DRGER; LCSC# C3655801
U5, U8, U11: STM32G071K8U6; MPN STM32G071K8U6; LCSC# C724237
U16, U17, U18: ACS711xEXLT-31AB; ACS711KEXLT-31AB-T; MPN ACS711KEXLT-31AB-T; LCSC# C146412

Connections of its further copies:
/ESC Module 2/BEMF_A: R23.1, R24.2, R30.2, U5.31 (PB7)
/ESC Module 2/BEMF_B: R25.1, R26.2, R31.2, U5.27 (PB3)
/ESC Module 2/BEMF_C: R28.1, R29.2, R32.2, U5.9 (PA2)
/ESC Module 2/GHA: U4.19 (GHA); also elsewhere on the board
/ESC Module 2/GHB: U4.16 (GHB); also elsewhere on the board
/ESC Module 2/GHC: U4.13 (GHC); also elsewhere on the board
/ESC Module 2/GLA: U4.11 (GLA); also elsewhere on the board
/ESC Module 2/GLB: U4.10 (GLB); also elsewhere on the board
/ESC Module 2/GLC: U4.9 (GLC); also elsewhere on the board
/ESC Module 2/HA: U4.22 (INHA), U5.21 (PA10)
/ESC Module 2/HB: U4.23 (INHB), U5.19 (PA9)
/ESC Module 2/HC: U4.24 (INHC), U5.18 (PA8)
/ESC Module 2/LA: U4.1 (INLA), U5.16 (PB1)
/ESC Module 2/LB: U4.2 (INLB), U5.15 (PB0)
/ESC Module 2/LC: U4.3 (INLC), U5.14 (PA7)
/ESC Module 2/PHASE_A: C13.2, J7.1 (Pin_1_1), R24.1, U4.18 (SHA); also elsewhere on the board
/ESC Module 2/PHASE_B: C14.2, J8.1 (Pin_1_1), R26.1, U4.15 (SHB); also elsewhere on the board
/ESC Module 2/PHASE_C: C17.2, J9.1 (Pin_1_1), R29.1, U4.12 (SHC); also elsewhere on the board
/ESC Module 2/SNS_CURR: U5.12 (PA5), U16.9 (VIOUT)
/ESC Module 2/SWCLK: TP7.1 (1_1), U5.25 (PA14-BOOT0)
/ESC Module 2/SWDIO: TP6.1 (1_1), U5.24 (PA13)
/ESC Module 2/VIRTUAL: R23.2, R25.2, R28.2, U5.10 (PA3)
/ESC Module 2/V_FET: C73.1, C74.1, C75.1, U16.2 (IP-); also elsewhere on the board
/ESC Module 2/nRST: C18.1, R22.1, TP5.1 (1_1), U5.6 (PF2-NRST)
/ESC Module 3/BEMF_A: R40.1, R41.2, R47.2, U8.31 (PB7)
/ESC Module 3/BEMF_B: R42.1, R43.2, R48.2, U8.27 (PB3)
/ESC Module 3/BEMF_C: R45.1, R46.2, R49.2, U8.9 (PA2)
/ESC Module 3/GHA: U7.19 (GHA); also elsewhere on the board
/ESC Module 3/GHB: U7.16 (GHB); also elsewhere on the board
/ESC Module 3/GHC: U7.13 (GHC); also elsewhere on the board
/ESC Module 3/GLA: U7.11 (GLA); also elsewhere on the board
/ESC Module 3/GLB: U7.10 (GLB); also elsewhere on the board
/ESC Module 3/GLC: U7.9 (GLC); also elsewhere on the board
/ESC Module 3/HA: U7.22 (INHA), U8.21 (PA10)
/ESC Module 3/HB: U7.23 (INHB), U8.19 (PA9)
/ESC Module 3/HC: U7.24 (INHC), U8.18 (PA8)
/ESC Module 3/LA: U7.1 (INLA), U8.16 (PB1)
/ESC Module 3/LB: U7.2 (INLB), U8.15 (PB0)
/ESC Module 3/LC: U7.3 (INLC), U8.14 (PA7)
/ESC Module 3/PHASE_A: C22.2, J10.1 (Pin_1_1), R41.1, U7.18 (SHA); also elsewhere on the board
/ESC Module 3/PHASE_B: C23.2, J11.1 (Pin_1_1), R43.1, U7.15 (SHB); also elsewhere on the board
/ESC Module 3/PHASE_C: C26.2, J12.1 (Pin_1_1), R46.1, U7.12 (SHC); also elsewhere on the board
/ESC Module 3/SNS_CURR: U8.12 (PA5), U17.9 (VIOUT)
/ESC Module 3/SWCLK: TP11.1 (1_1), U8.25 (PA14-BOOT0)
/ESC Module 3/SWDIO: TP10.1 (1_1), U8.24 (PA13)
/ESC Module 3/VIRTUAL: R40.2, R42.2, R45.2, U8.10 (PA3)
/ESC Module 3/V_FET: C76.1, C77.1, C78.1, U17.2 (IP-); also elsewhere on the board
/ESC Module 3/nRST: C27.1, R39.1, TP9.1 (1_1), U8.6 (PF2-NRST)
/ESC Module 4/BEMF_A: R57.1, R58.2, R64.2, U11.31 (PB7)
/ESC Module 4/BEMF_B: R59.1, R60.2, R65.2, U11.27 (PB3)
/ESC Module 4/BEMF_C: R62.1, R63.2, R66.2, U11.9 (PA2)
/ESC Module 4/GHA: U10.19 (GHA); also elsewhere on the board
/ESC Module 4/GHB: U10.16 (GHB); also elsewhere on the board
/ESC Module 4/GHC: U10.13 (GHC); also elsewhere on the board
/ESC Module 4/GLA: U10.11 (GLA); also elsewhere on the board
/ESC Module 4/GLB: U10.10 (GLB); also elsewhere on the board
/ESC Module 4/GLC: U10.9 (GLC); also elsewhere on the board
/ESC Module 4/HA: U10.22 (INHA), U11.21 (PA10)
/ESC Module 4/HB: U10.23 (INHB), U11.19 (PA9)
/ESC Module 4/HC: U10.24 (INHC), U11.18 (PA8)
/ESC Module 4/LA: U10.1 (INLA), U11.16 (PB1)
/ESC Module 4/LB: U10.2 (INLB), U11.15 (PB0)
/ESC Module 4/LC: U10.3 (INLC), U11.14 (PA7)
/ESC Module 4/PHASE_A: C31.2, J13.1 (Pin_1_1), R58.1, U10.18 (SHA); also elsewhere on the board
/ESC Module 4/PHASE_B: C32.2, J14.1 (Pin_1_1), R60.1, U10.15 (SHB); also elsewhere on the board
/ESC Module 4/PHASE_C: C35.2, J15.1 (Pin_1_1), R63.1, U10.12 (SHC); also elsewhere on the board
/ESC Module 4/SNS_CURR: U11.12 (PA5), U18.9 (VIOUT)
/ESC Module 4/SWCLK: TP15.1 (1_1), U11.25 (PA14-BOOT0)
/ESC Module 4/SWDIO: TP14.1 (1_1), U11.24 (PA13)
/ESC Module 4/VIRTUAL: R57.2, R59.2, R62.2, U11.10 (PA3)
/ESC Module 4/V_FET: C79.1, C80.1, C81.1, U18.2 (IP-); also elsewhere on the board
/ESC Module 4/nRST: C36.1, R56.1, TP13.1 (1_1), U11.6 (PF2-NRST)
/M2: U5.28 (PB4); also elsewhere on the board
/M3: U8.28 (PB4); also elsewhere on the board
/M4: U11.28 (PB4); also elsewhere on the board
GND: C11.2, C12.2, C15.2, C16.2, C18.2, C19.2, C20.2, C21.2, C24.2, C25.2, C27.2, C28.2, C29.2, C30.2, C33.2, C34.2, C36.2, C37.2, C73.2, C74.2, C75.2, C76.2, C77.2, C78.2, C79.2, C80.2, C81.2, R30.1, R31.1, R32.1, R47.1, R48.1, R49.1, R64.1, R65.1, R66.1, U4.5 (MODE), U4.6 (GND), U4.21 (DT), U4.25 (PowerPAD), U5.5 (VSS), U7.5 (MODE), U7.6 (GND), U7.21 (DT), U7.25 (PowerPAD), U8.5 (VSS), U10.5 (MODE), U10.6 (GND), U10.21 (DT), U10.25 (PowerPAD), U11.5 (VSS), U16.3 (GND), U17.3 (GND), U18.3 (GND); also elsewhere on the board
unnamed: C13.1, U4.20 (BSTA)
unnamed: C14.1, U4.17 (BSTB)
unnamed: C17.1, U4.14 (BSTC)
unnamed: C22.1, U7.20 (BSTA)
unnamed: C23.1, U7.17 (BSTB)
unnamed: C26.1, U7.14 (BSTC)
unnamed: C31.1, U10.20 (BSTA)
unnamed: C32.1, U10.17 (BSTB)
unnamed: C35.1, U10.14 (BSTC)
TELEM: U5.30 (PB6), U8.30 (PB6), U11.30 (PB6); also elsewhere on the board
V_3V3: C11.1, C12.1, C19.1, C20.1, C21.1, C28.1, C29.1, C30.1, C37.1, R22.2, R39.2, R56.2, U5.4 (VDD), U8.4 (VDD), U11.4 (VDD), U16.10 (VCC), U17.10 (VCC), U18.10 (VCC); also elsewhere on the board
V_10V: C15.1, C16.1, C24.1, C25.1, C33.1, C34.1, U4.4 (GVDD), U7.4 (GVDD), U10.4 (GVDD); also elsewhere on the board
V_BAT: U16.1 (IP+), U17.1 (IP+), U18.1 (IP+); also elsewhere on the board

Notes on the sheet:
Current sensing
10uF * 3
Back-EMF sensing
Gate driver + half bridges
MLCCs
MCU
Conns
~1.27V - ~2.55V

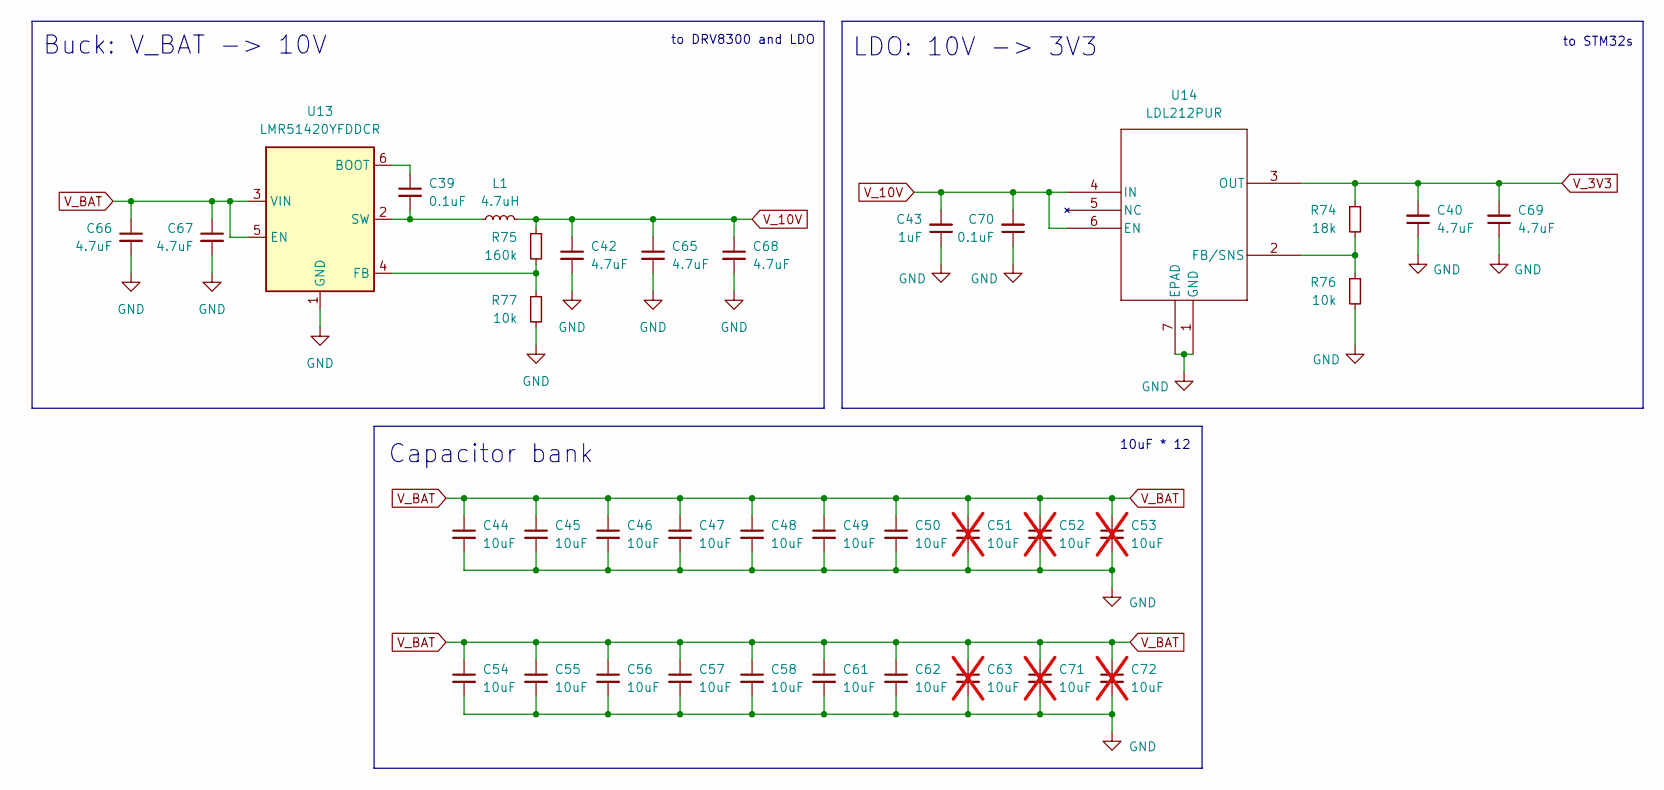
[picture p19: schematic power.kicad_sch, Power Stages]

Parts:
C39, C70: 0.1uF; C_0402; MPN CGA2B3X7R1V104KT0Y0F; LCSC# C343047
C40, C42, C65, C68, C69: 4.7uF; C_0402; MPN TDK105CBJ475MV-F; LCSC# C22385335
C43: 1uF; C_0402; MPN GRM155R6YA105KE11J; LCSC# C3835721
C44, C45, C46, C47, C48, C49, C50, C54, C55, C56, C57, C58, C61, C62: 10uF; C_0805_2012Metric; MPN GRM21BR6YA106KE43L; LCSC# C162422
C51, C52, C53, C63, C71, C72: 10uF; C_0805_2012Metric; MPN GRM21BR6YA106KE43L; LCSC# C162422; not fitted
C66, C67: 4.7uF; C_0603_1608Metric; MPN CL10A475KL8NRNC; LCSC# C307467
L1: 4.7uH; L_1210_3225Metric; MPN BCL322520RT-4R7M-D; LCSC# C3224690
R74: 18k; R_0402; MPN RC0402FR-0718KL; LCSC# C138044
R75: 160k; R_0402; MPN RC0402FR-07160KL; LCSC# C273334
R76, R77: 10k; R_0402; MPN RC0402FR-0710KL; LCSC# C60490
U13: LMR51420YFDDCR; MPN LMR51420YFDDCR; LCSC# C7296200
U14: LDL212PUR; LDLPUR212; MPN LDL212PUR; LCSC# C2969849

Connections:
GND: C40.1, C42.2, C43.1, C44.2, C45.2, C46.2, C47.2, C48.2, C49.2, C50.2, C51.2, C52.2, C53.2, C54.2, C55.2, C56.2, C57.2, C58.2, C61.2, C62.2, C63.2, C65.2, C66.2, C67.2, C68.2, C69.1, C70.1, C71.2, C72.2, R76.2, R77.2, U13.1 (GND), U14.1 (GND), U14.7 (EPAD); also elsewhere on the board
unnamed: C39.1, U13.6 (BOOT)
unnamed: R75.2, R77.1, U13.4 (FB)
unnamed: C39.2, L1.1, U13.2 (SW)
unnamed: R74.2, R76.1, U14.2 (FB/SNS)
V_3V3: C40.2, C69.2, R74.1, U14.3 (OUT); also elsewhere on the board
V_10V: C42.1, C43.2, C65.1, C68.1, C70.2, L1.2, R75.1, U14.4 (IN), U14.6 (EN); also elsewhere on the board
V_BAT: C44.1, C45.1, C46.1, C47.1, C48.1, C49.1, C50.1, C51.1, C52.1, C53.1, C54.1, C55.1, C56.1, C57.1, C58.1, C61.1, C62.1, C63.1, C66.1, C67.1, C71.1, C72.1, U13.3 (VIN), U13.5 (EN); also elsewhere on the board

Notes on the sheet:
Buck: V_BAT -> 10V
Capacitor bank
to DRV8300 and LDO
to STM32s
10uF * 12
LDO: 10V -> 3V3

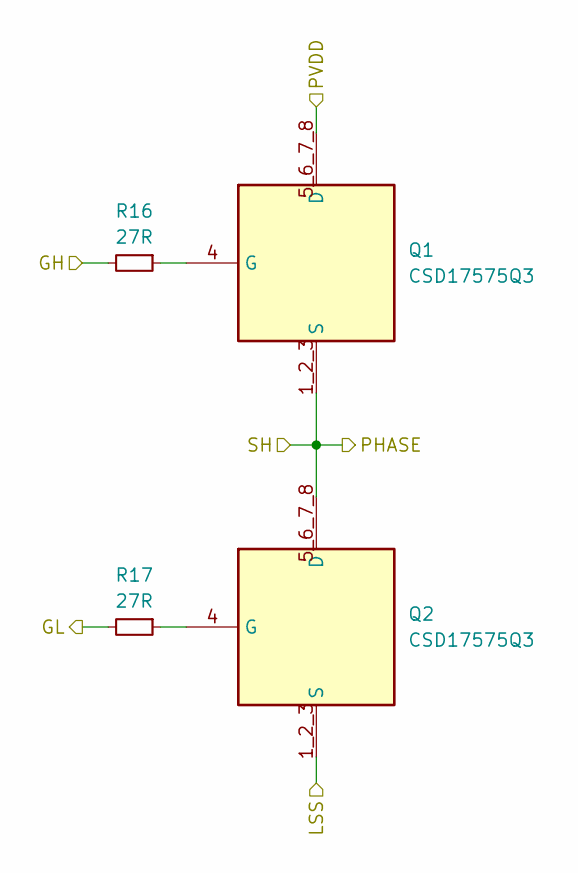
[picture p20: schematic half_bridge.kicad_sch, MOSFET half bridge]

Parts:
Q1, Q2: CSD17575Q3; MPN CSD17575Q3; LCSC# C529277
R16, R17: 27R; R_0402; MPN RC0402FR-0727RL; LCSC# C138021

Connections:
/ESC Module 1/GHA: R16.2; also elsewhere on the board
/ESC Module 1/GLA: R17.2; also elsewhere on the board
/ESC Module 1/PHASE_A: Q1.1_2_3 (S), Q2.5_6_7_8 (D); also elsewhere on the board
/ESC Module 1/V_FET: Q1.5_6_7_8 (D); also elsewhere on the board
GND: Q2.1_2_3 (S); also elsewhere on the board
unnamed: Q1.4 (G), R16.1
unnamed: Q2.4 (G), R17.1

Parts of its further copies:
Q3, Q4, Q5, Q6, Q7, Q8, Q9, Q10, Q11, Q12, Q13, Q14, Q15, Q16, Q17, Q18, Q19, Q20, Q21, Q22, Q23, Q24: CSD17575Q3; MPN CSD17575Q3; LCSC# C529277
R18, R19, R20, R21, R33, R34, R35, R36, R37, R38, R50, R51, R52, R53, R54, R55, R67, R68, R69, R70, R71, R72: 27R; R_0402; MPN RC0402FR-0727RL; LCSC# C138021

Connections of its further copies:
/ESC Module 1/GHB: R18.2; also elsewhere on the board
/ESC Module 1/GHC: R20.2; also elsewhere on the board
/ESC Module 1/GLB: R19.2; also elsewhere on the board
/ESC Module 1/GLC: R21.2; also elsewhere on the board
/ESC Module 1/PHASE_B: Q3.1_2_3 (S), Q4.5_6_7_8 (D); also elsewhere on the board
/ESC Module 1/PHASE_C: Q5.1_2_3 (S), Q6.5_6_7_8 (D); also elsewhere on the board
/ESC Module 1/V_FET: Q3.5_6_7_8 (D), Q5.5_6_7_8 (D); also elsewhere on the board
/ESC Module 2/GHA: R37.2; also elsewhere on the board
/ESC Module 2/GHB: R33.2; also elsewhere on the board
/ESC Module 2/GHC: R35.2; also elsewhere on the board
/ESC Module 2/GLA: R38.2; also elsewhere on the board
/ESC Module 2/GLB: R34.2; also elsewhere on the board
/ESC Module 2/GLC: R36.2; also elsewhere on the board
/ESC Module 2/PHASE_A: Q11.1_2_3 (S), Q12.5_6_7_8 (D); also elsewhere on the board
/ESC Module 2/PHASE_B: Q7.1_2_3 (S), Q8.5_6_7_8 (D); also elsewhere on the board
/ESC Module 2/PHASE_C: Q9.1_2_3 (S), Q10.5_6_7_8 (D); also elsewhere on the board
/ESC Module 2/V_FET: Q7.5_6_7_8 (D), Q9.5_6_7_8 (D), Q11.5_6_7_8 (D); also elsewhere on the board
/ESC Module 3/GHA: R54.2; also elsewhere on the board
/ESC Module 3/GHB: R50.2; also elsewhere on the board
/ESC Module 3/GHC: R52.2; also elsewhere on the board
/ESC Module 3/GLA: R55.2; also elsewhere on the board
/ESC Module 3/GLB: R51.2; also elsewhere on the board
/ESC Module 3/GLC: R53.2; also elsewhere on the board
/ESC Module 3/PHASE_A: Q17.1_2_3 (S), Q18.5_6_7_8 (D); also elsewhere on the board
/ESC Module 3/PHASE_B: Q13.1_2_3 (S), Q14.5_6_7_8 (D); also elsewhere on the board
/ESC Module 3/PHASE_C: Q15.1_2_3 (S), Q16.5_6_7_8 (D); also elsewhere on the board
/ESC Module 3/V_FET: Q13.5_6_7_8 (D), Q15.5_6_7_8 (D), Q17.5_6_7_8 (D); also elsewhere on the board
/ESC Module 4/GHA: R71.2; also elsewhere on the board
/ESC Module 4/GHB: R67.2; also elsewhere on the board
/ESC Module 4/GHC: R69.2; also elsewhere on the board
/ESC Module 4/GLA: R72.2; also elsewhere on the board
/ESC Module 4/GLB: R68.2; also elsewhere on the board
/ESC Module 4/GLC: R70.2; also elsewhere on the board
/ESC Module 4/PHASE_A: Q23.1_2_3 (S), Q24.5_6_7_8 (D); also elsewhere on the board
/ESC Module 4/PHASE_B: Q19.1_2_3 (S), Q20.5_6_7_8 (D); also elsewhere on the board
/ESC Module 4/PHASE_C: Q21.1_2_3 (S), Q22.5_6_7_8 (D); also elsewhere on the board
/ESC Module 4/V_FET: Q19.5_6_7_8 (D), Q21.5_6_7_8 (D), Q23.5_6_7_8 (D); also elsewhere on the board
GND: Q4.1_2_3 (S), Q6.1_2_3 (S), Q8.1_2_3 (S), Q10.1_2_3 (S), Q12.1_2_3 (S), Q14.1_2_3 (S), Q16.1_2_3 (S), Q18.1_2_3 (S), Q20.1_2_3 (S), Q22.1_2_3 (S), Q24.1_2_3 (S); also elsewhere on the board
unnamed: Q3.4 (G), R18.1
unnamed: Q4.4 (G), R19.1
unnamed: Q5.4 (G), R20.1
unnamed: Q6.4 (G), R21.1
unnamed: Q7.4 (G), R33.1
unnamed: Q8.4 (G), R34.1
unnamed: Q9.4 (G), R35.1
unnamed: Q10.4 (G), R36.1
unnamed: Q11.4 (G), R37.1
unnamed: Q12.4 (G), R38.1
unnamed: Q13.4 (G), R50.1
unnamed: Q14.4 (G), R51.1
unnamed: Q15.4 (G), R52.1
unnamed: Q16.4 (G), R53.1
unnamed: Q17.4 (G), R54.1
unnamed: Q18.4 (G), R55.1
unnamed: Q19.4 (G), R67.1
unnamed: Q20.4 (G), R68.1
unnamed: Q21.4 (G), R69.1
unnamed: Q22.4 (G), R70.1
unnamed: Q23.4 (G), R71.1
unnamed: Q24.4 (G), R72.1

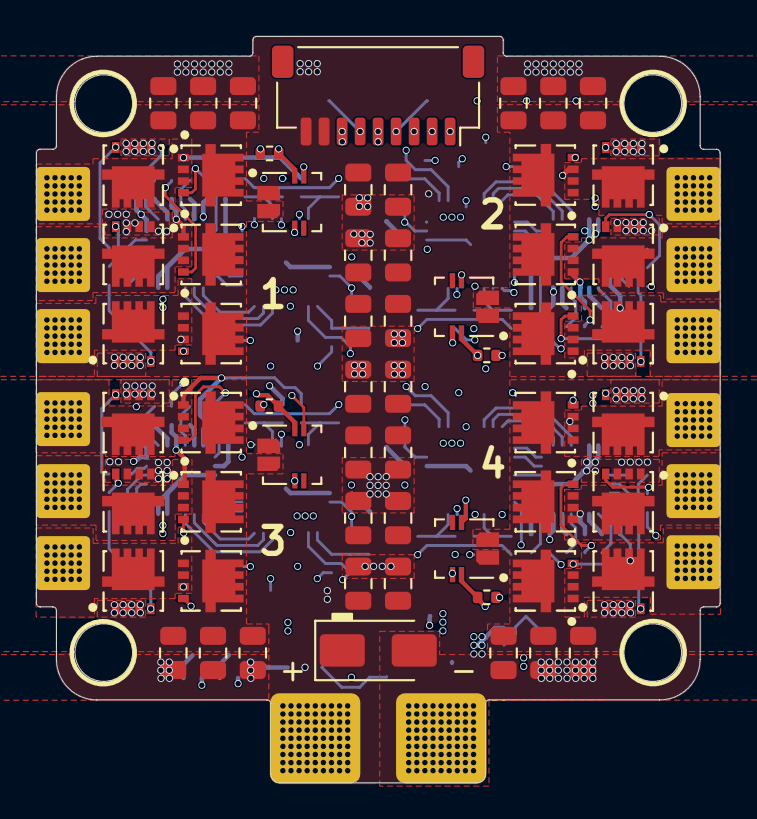
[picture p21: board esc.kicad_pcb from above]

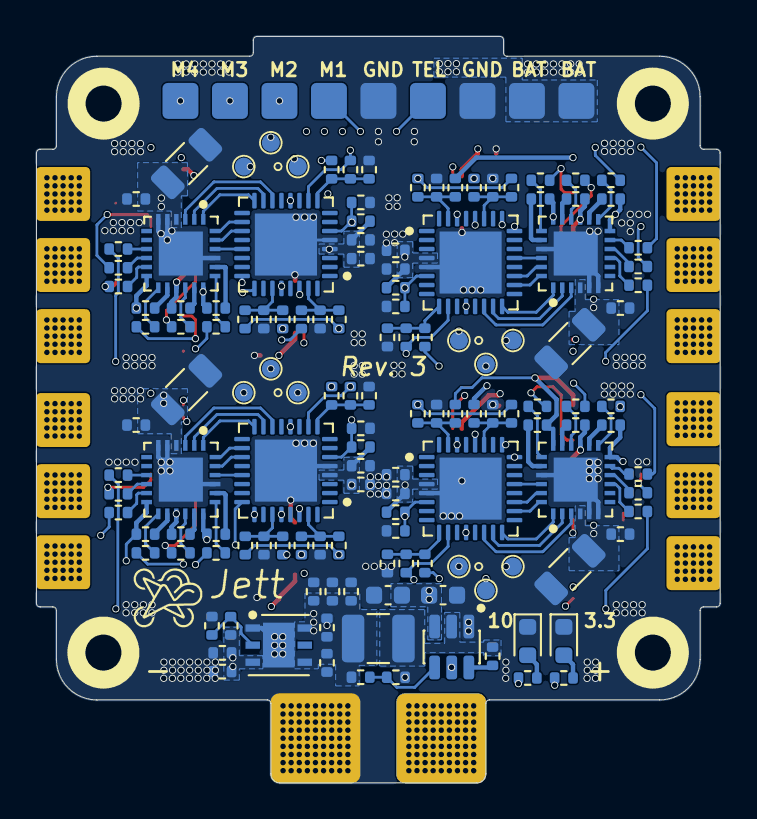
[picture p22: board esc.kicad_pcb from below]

Board: 8 copper layers, 38.0 x 41.5 mm, 215 parts (140 on the bottom side), 147 nets.

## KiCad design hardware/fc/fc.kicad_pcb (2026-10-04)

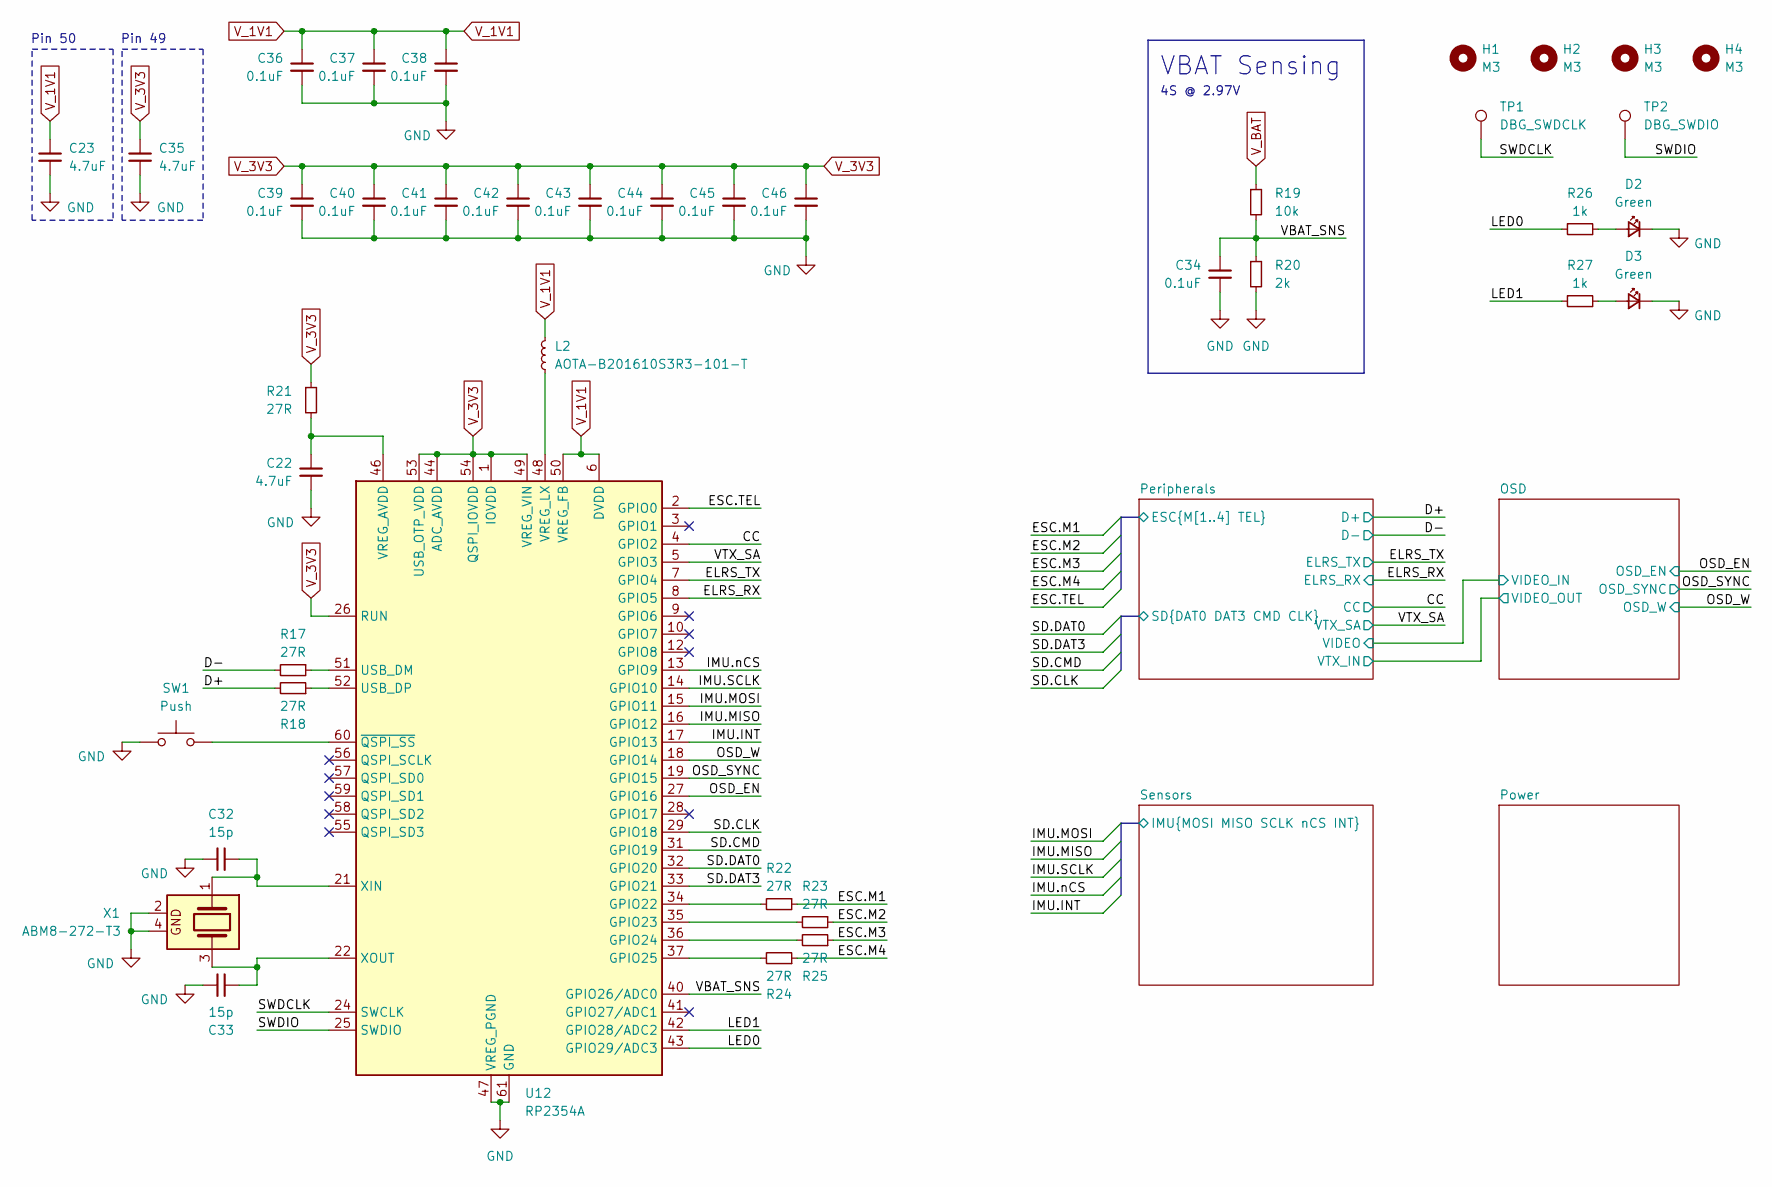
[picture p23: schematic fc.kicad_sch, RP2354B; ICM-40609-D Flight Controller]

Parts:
C22, C23, C35: 4.7uF; C_0402
C32, C33: 15p; C_0402
C34, C36, C37, C38, C39, C40, C41, C42, C43, C44, C45, C46: 0.1uF; C_0402
D2, D3: Green; LED_0603_1608Metric; MPN VLMTG1400-GS08; LCSC# C3000897
H1, H2, H3, H4: M3; Mount_M3_K0.5
L2: AOTA-B201610S3R3-101-T; L_0806
R17, R18, R21, R22, R23, R24, R25: 27R; R_0402
R19: 10k; R_0402
R20: 2k; R_0402
R26, R27: 1k; R_0402; MPN RC0402FR-071KL; LCSC# C106235
SW1: Push; Push_2x3
TP1: DBG_SWDCLK; Debug_Pad_D1
TP2: DBG_SWDIO; Debug_Pad_D1
U12: RP2354A
X1: ABM8-272-T3; Crystal_4P_3.2x2.5mm

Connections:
/CC: U12.4 (GPIO2); also elsewhere on the board
/D+: R18.2; also elsewhere on the board
/D-: R17.2; also elsewhere on the board
/ELRS_RX: U12.8 (GPIO5); also elsewhere on the board
/ELRS_TX: U12.7 (GPIO4); also elsewhere on the board
/LED0: R26.1, U12.43 (GPIO29/ADC3)
/LED1: R27.1, U12.42 (GPIO28/ADC2)
/OSD_EN: U12.27 (GPIO16); also elsewhere on the board
/OSD_SYNC: U12.19 (GPIO15); also elsewhere on the board
/OSD_W: U12.18 (GPIO14); also elsewhere on the board
/Peripherals/ESC.M1: R22.1; also elsewhere on the board
/Peripherals/ESC.M2: R23.1; also elsewhere on the board
/Peripherals/ESC.M3: R25.1; also elsewhere on the board
/Peripherals/ESC.M4: R24.1; also elsewhere on the board
/Peripherals/ESC.TEL: U12.2 (GPIO0); also elsewhere on the board
/Peripherals/SD.CLK: U12.29 (GPIO18); also elsewhere on the board
/Peripherals/SD.CMD: U12.31 (GPIO19); also elsewhere on the board
/Peripherals/SD.DAT0: U12.32 (GPIO20); also elsewhere on the board
/Peripherals/SD.DAT3: U12.33 (GPIO21); also elsewhere on the board
/SWDCLK: TP1.1 (1_1), U12.24 (SWCLK)
/SWDIO: TP2.1 (1_1), U12.25 (SWDIO)
/Sensors/IMU.INT: U12.17 (GPIO13); also elsewhere on the board
/Sensors/IMU.MISO: U12.16 (GPIO12); also elsewhere on the board
/Sensors/IMU.MOSI: U12.15 (GPIO11); also elsewhere on the board
/Sensors/IMU.SCLK: U12.14 (GPIO10); also elsewhere on the board
/Sensors/IMU.nCS: U12.13 (GPIO9); also elsewhere on the board
/VBAT_SNS: C34.1, R19.2, R20.1, U12.40 (GPIO26/ADC0)
/VTX_SA: U12.5 (GPIO3); also elsewhere on the board
GND: C22.2, C23.2, C32.2, C33.2, C34.2, C35.2, C36.2, C37.2, C38.2, C39.2, C40.2, C41.2, C42.2, C43.2, C44.2, C45.2, C46.2, D2.1 (K), D3.1 (K), R20.2, SW1.1, U12.47 (VREG_PGND), U12.61 (GND), X1.2, X1.4; also elsewhere on the board
unnamed: D2.2 (A), R26.2
unnamed: D3.2 (A), R27.2
unnamed: R22.2, U12.34 (GPIO22)
unnamed: R23.2, U12.35 (GPIO23)
unnamed: R25.2, U12.36 (GPIO24)
unnamed: R24.2, U12.37 (GPIO25)
unnamed: R17.1, U12.51 (USB_DM)
unnamed: R18.1, U12.52 (USB_DP)
unnamed: C22.1, R21.2, U12.46 (VREG_AVDD)
unnamed: L2.1, U12.48 (VREG_LX)
unnamed: C32.1, U12.21 (XIN), X1.1
unnamed: C33.1, U12.22 (XOUT), X1.3
unnamed: SW1.2, U12.60 (~QSPI_SS)
V_1V1: C23.1, C36.1, C37.1, C38.1, L2.2, U12.6 (DVDD), U12.23 (DVDD), U12.39 (DVDD), U12.50 (VREG_FB)
V_3V3: C35.1, C39.1, C40.1, C41.1, C42.1, C43.1, C44.1, C45.1, C46.1, R21.1, U12.1 (IOVDD), U12.11 (IOVDD), U12.20 (IOVDD), U12.26 (RUN), U12.30 (IOVDD), U12.38 (IOVDD), U12.44 (ADC_AVDD), U12.45 (IOVDD), U12.49 (VREG_VIN), U12.53 (USB_OTP_VDD), U12.54 (QSPI_IOVDD); also elsewhere on the board
V_BAT: R19.1; also elsewhere on the board

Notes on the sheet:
Pin 50
VBAT Sensing
4S @ 2.97V
Pin 49

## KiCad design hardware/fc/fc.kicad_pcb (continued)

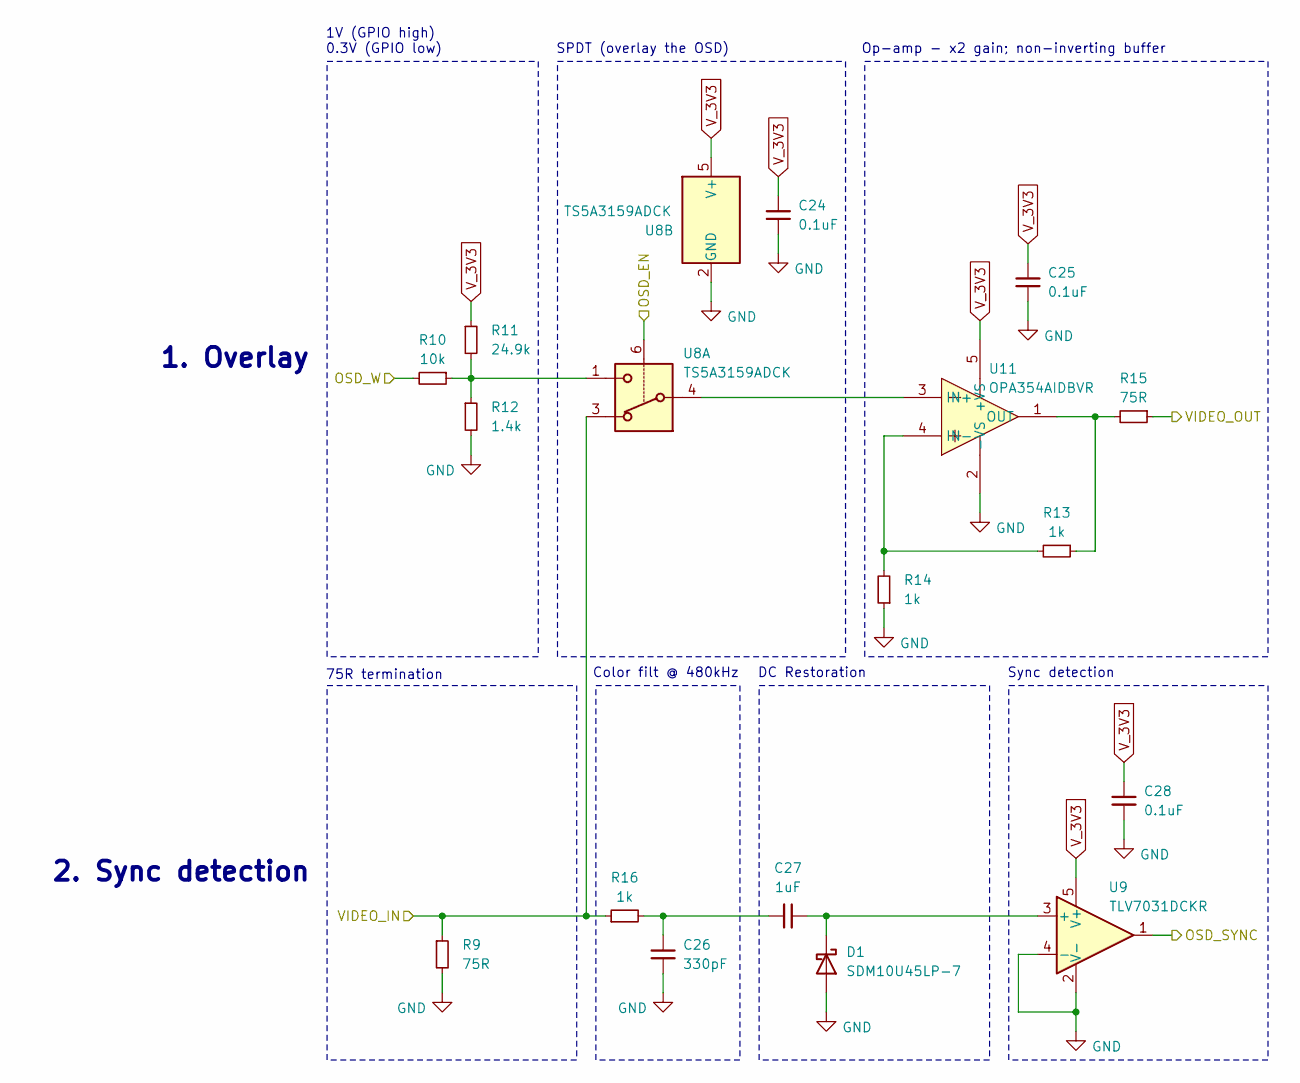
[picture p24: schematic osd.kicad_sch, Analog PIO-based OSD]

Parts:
C24, C25, C28: 0.1uF; C_0402
C26: 330pF; C_0402
C27: 1uF; C_0402
D1: SDM10U45LP-7; D_0402
R9, R15: 75R; R_0402
R10: 10k; R_0402
R11: 24.9k; R_0402
R12: 1.4k; R_0402
R13, R14, R16: 1k; R_0402
U8: TS5A3159ADCK
U9: TLV7031DCKR
U11: OPA354AIDBVR; MPN COS8051SOT; LCSC C7463385

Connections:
/OSD/VIDEO_IN: R9.1, R16.1, U8.3; also elsewhere on the board
/OSD/VIDEO_OUT: R15.1; also elsewhere on the board
/OSD_EN: U8.6; also elsewhere on the board
/OSD_SYNC: U9.1; also elsewhere on the board
/OSD_W: R10.2; also elsewhere on the board
GND: C24.2, C25.2, C26.2, C28.2, D1.2 (A), R9.2, R12.2, R14.1, U8.2 (GND), U9.2 (V-), U9.4 (-), U11.2 (-VS); also elsewhere on the board
unnamed: C26.1, C27.2, R16.2
unnamed: C27.1, D1.1 (K), U9.3 (+)
unnamed: R10.1, R11.2, R12.1, U8.1
unnamed: U8.4, U11.3 (IN+)
unnamed: R13.2, R14.2, U11.4 (IN-)
unnamed: R13.1, R15.2, U11.1 (OUT)
V_3V3: C24.1, C25.1, C28.1, R11.1, U8.5 (V+), U9.5 (V+), U11.5 (+VS); also elsewhere on the board

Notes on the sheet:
75R termination
Op-amp - x2 gain; non-inverting buffer
2. Sync detection
1V (GPIO high) 0.3V (GPIO low)
Color filt @ 480kHz
Sync detection
DC Restoration
SPDT (overlay the OSD)
1. Overlay

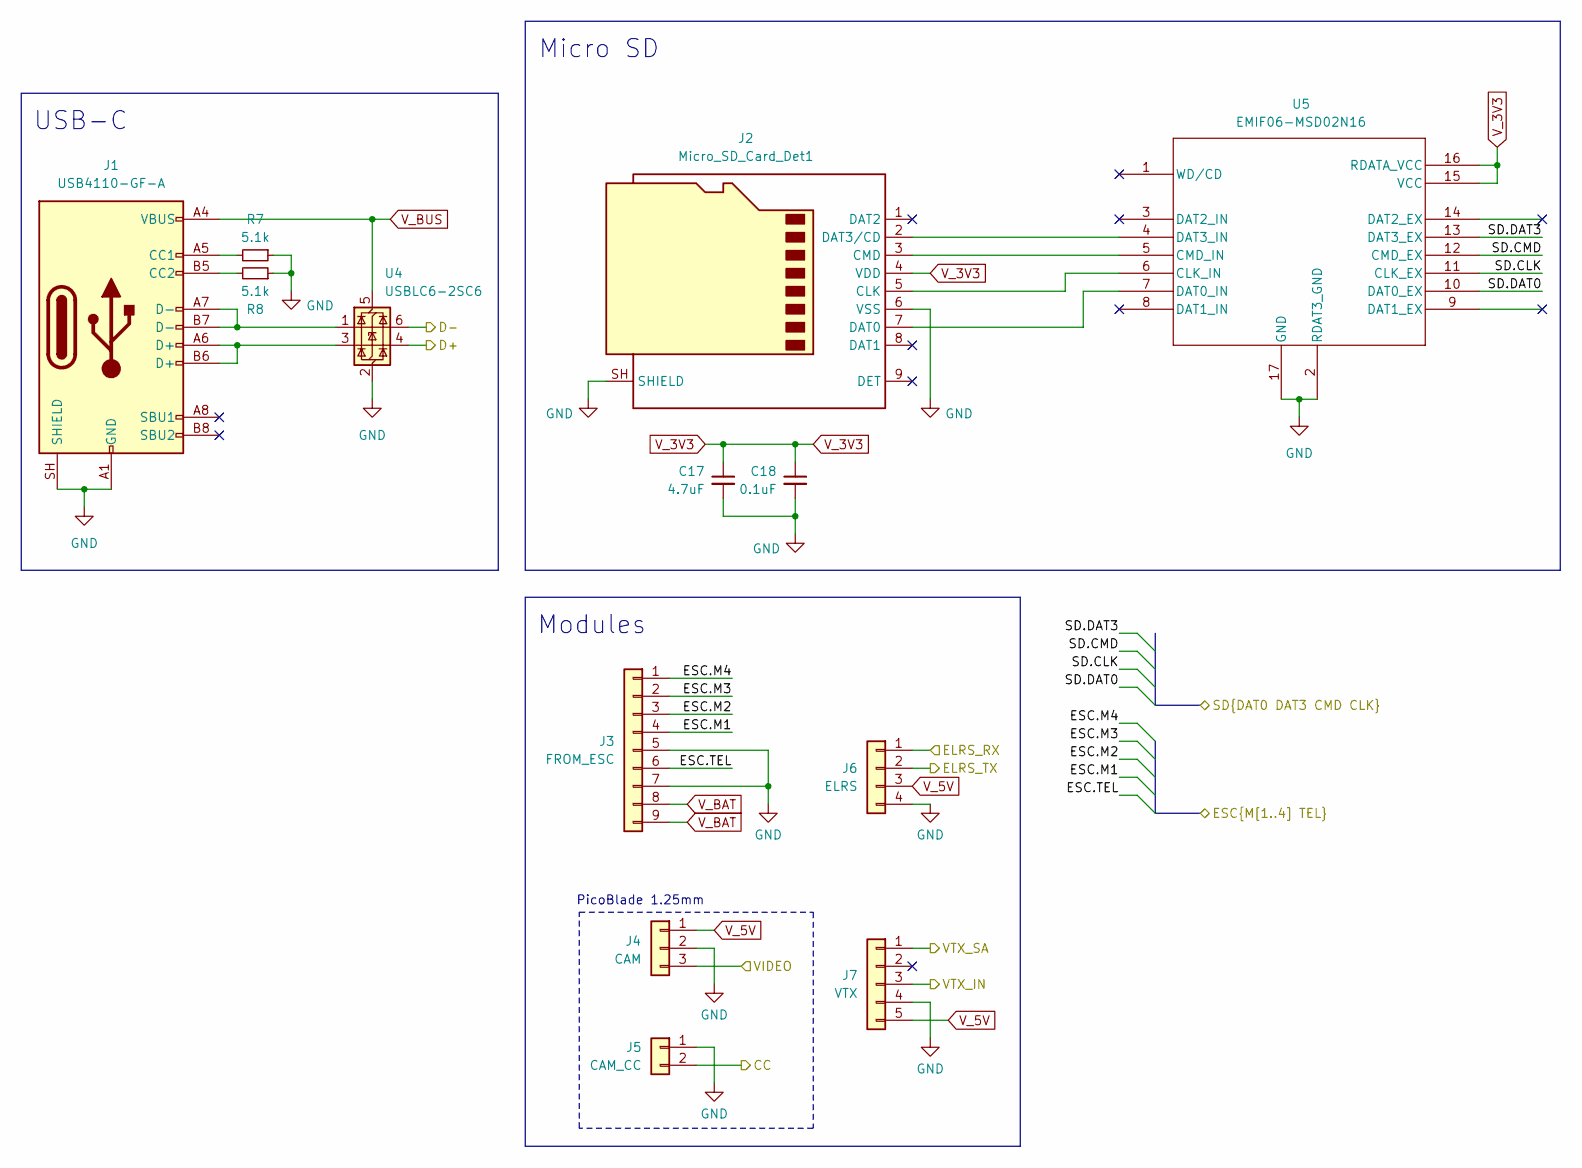
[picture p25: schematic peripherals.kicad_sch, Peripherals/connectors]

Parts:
C17: 4.7uF; C_0402
C18: 0.1uF; C_0402
J1: USB4110-GF-A; USB_C_Receptacle_GCT_USB4110
J2: Micro_SD_Card_Det1; 0473092651
J3: FROM_ESC; JST_SH_SM09B-SRSS-TB_1x09-1MP_P1.00mm_Horizontal; MPN SM09B-SRSS-TB(LF)(SN); LCSC# C160408
J4: CAM; JST_SH_SM03B-SRSS-TB_1x03-1MP_P1.00mm_Horizontal
J5: CAM_CC; JST_SH_SM02B-SRSS-TB_1x02-1MP_P1.00mm_Horizontal
J6: ELRS; JST_SH_SM04B-SRSS-TB_1x04-1MP_P1.00mm_Horizontal
J7: VTX; JST_SH_SM05B-SRSS-TB_1x05-1MP_P1.00mm_Horizontal
R7, R8: 5.1k; R_0402
U4: USBLC6-2SC6
U5: EMIF06-MSD02N16

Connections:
/CC: J5.2; also elsewhere on the board
/D+: U4.4 (I/O2); also elsewhere on the board
/D-: U4.6 (I/O1); also elsewhere on the board
/ELRS_RX: J6.1; also elsewhere on the board
/ELRS_TX: J6.2; also elsewhere on the board
/OSD/VIDEO_IN: J4.3; also elsewhere on the board
/OSD/VIDEO_OUT: J7.3; also elsewhere on the board
/Peripherals/ESC.M1: J3.4; also elsewhere on the board
/Peripherals/ESC.M2: J3.3; also elsewhere on the board
/Peripherals/ESC.M3: J3.2; also elsewhere on the board
/Peripherals/ESC.M4: J3.1; also elsewhere on the board
/Peripherals/ESC.TEL: J3.6; also elsewhere on the board
/Peripherals/SD.CLK: U5.11 (CLK_EX); also elsewhere on the board
/Peripherals/SD.CMD: U5.12 (CMD_EX); also elsewhere on the board
/Peripherals/SD.DAT0: U5.10 (DAT0_EX); also elsewhere on the board
/Peripherals/SD.DAT3: U5.13 (DAT3_EX); also elsewhere on the board
/VTX_SA: J7.1; also elsewhere on the board
GND: C17.2, C18.2, J1.A1 (GND), J1.A12 (GND), J1.B1 (GND), J1.B12 (GND), J1.SH (SHIELD), J2.6 (VSS), J2.SH (SHIELD), J3.5, J3.7, J4.2, J5.1, J6.4, J7.4, R7.1, R8.1, U4.2 (GND), U5.2 (RDAT3_GND), U5.17 (GND); also elsewhere on the board
unnamed: J1.A5 (CC1), R7.2
unnamed: J1.B5 (CC2), R8.2
unnamed: J1.A6 (D+), J1.B6 (D+), U4.3 (I/O2)
unnamed: J1.A7 (D-), J1.B7 (D-), U4.1 (I/O1)
unnamed: J2.5 (CLK), U5.6 (CLK_IN)
unnamed: J2.3 (CMD), U5.5 (CMD_IN)
unnamed: J2.7 (DAT0), U5.7 (DAT0_IN)
unnamed: J2.2 (DAT3/CD), U5.4 (DAT3_IN)
V_3V3: C17.1, C18.1, J2.4 (VDD), U5.15 (VCC), U5.16 (RDATA_VCC); also elsewhere on the board
V_5V: J4.1, J6.3, J7.5; also elsewhere on the board
V_BAT: J3.8, J3.9; also elsewhere on the board
V_BUS: J1.A4 (VBUS), J1.A9 (VBUS), J1.B4 (VBUS), J1.B9 (VBUS), U4.5 (VBUS); also elsewhere on the board

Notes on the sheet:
USB-C
PicoBlade 1.25mm
Micro SD
Modules

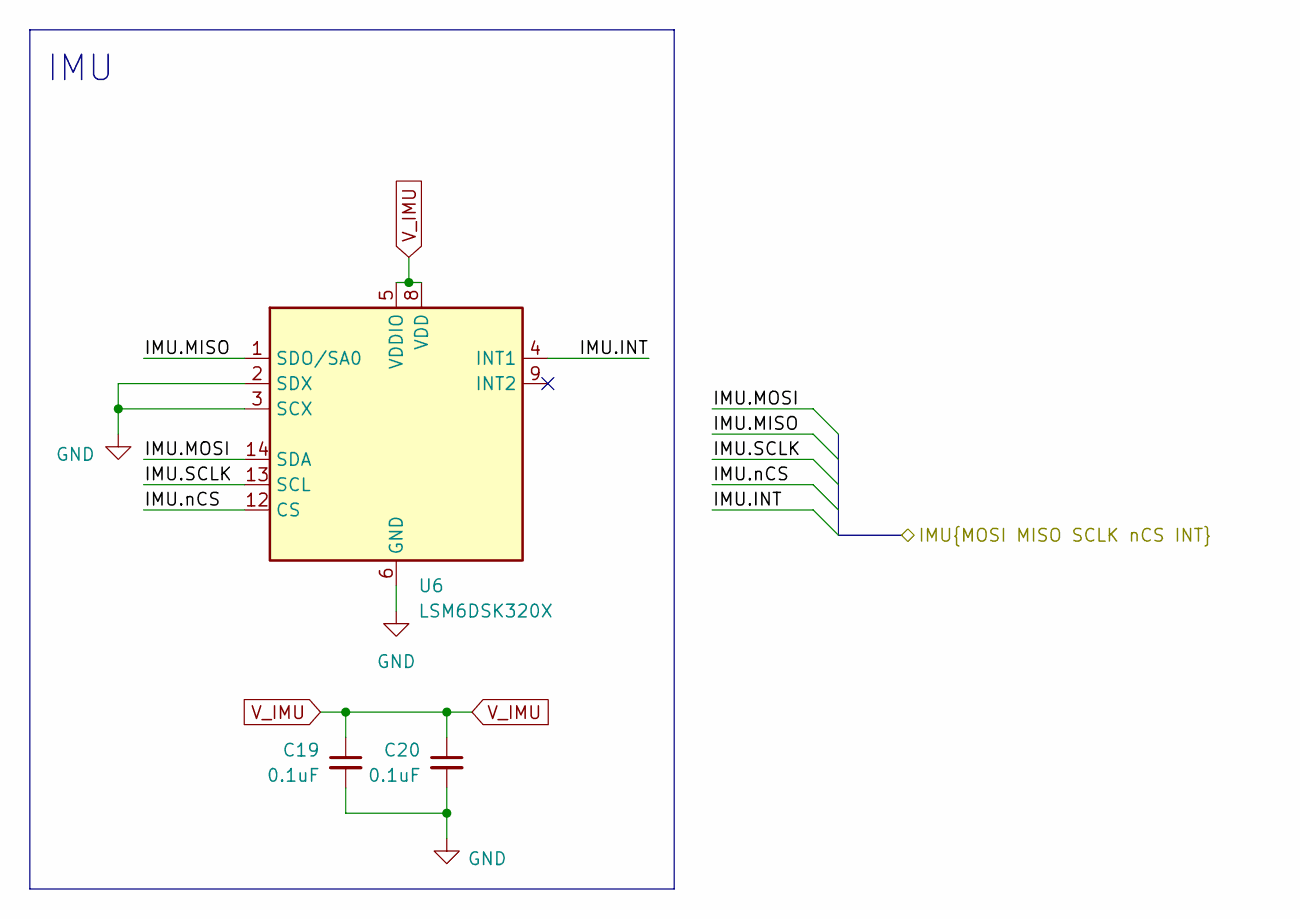
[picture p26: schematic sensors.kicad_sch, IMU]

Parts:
C19, C20: 0.1uF; C_0402
U6: LSM6DSK320X

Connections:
/Sensors/IMU.INT: U6.4 (INT1); also elsewhere on the board
/Sensors/IMU.MISO: U6.1 (SDO/SA0); also elsewhere on the board
/Sensors/IMU.MOSI: U6.14 (SDA); also elsewhere on the board
/Sensors/IMU.SCLK: U6.13 (SCL); also elsewhere on the board
/Sensors/IMU.nCS: U6.12 (CS); also elsewhere on the board
GND: C19.2, C20.2, U6.2 (SDX), U6.3 (SCX), U6.6 (GND), U6.7 (GND); also elsewhere on the board
V_IMU: C19.1, C20.1, U6.5 (VDDIO), U6.8 (VDD); also elsewhere on the board

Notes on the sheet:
IMU

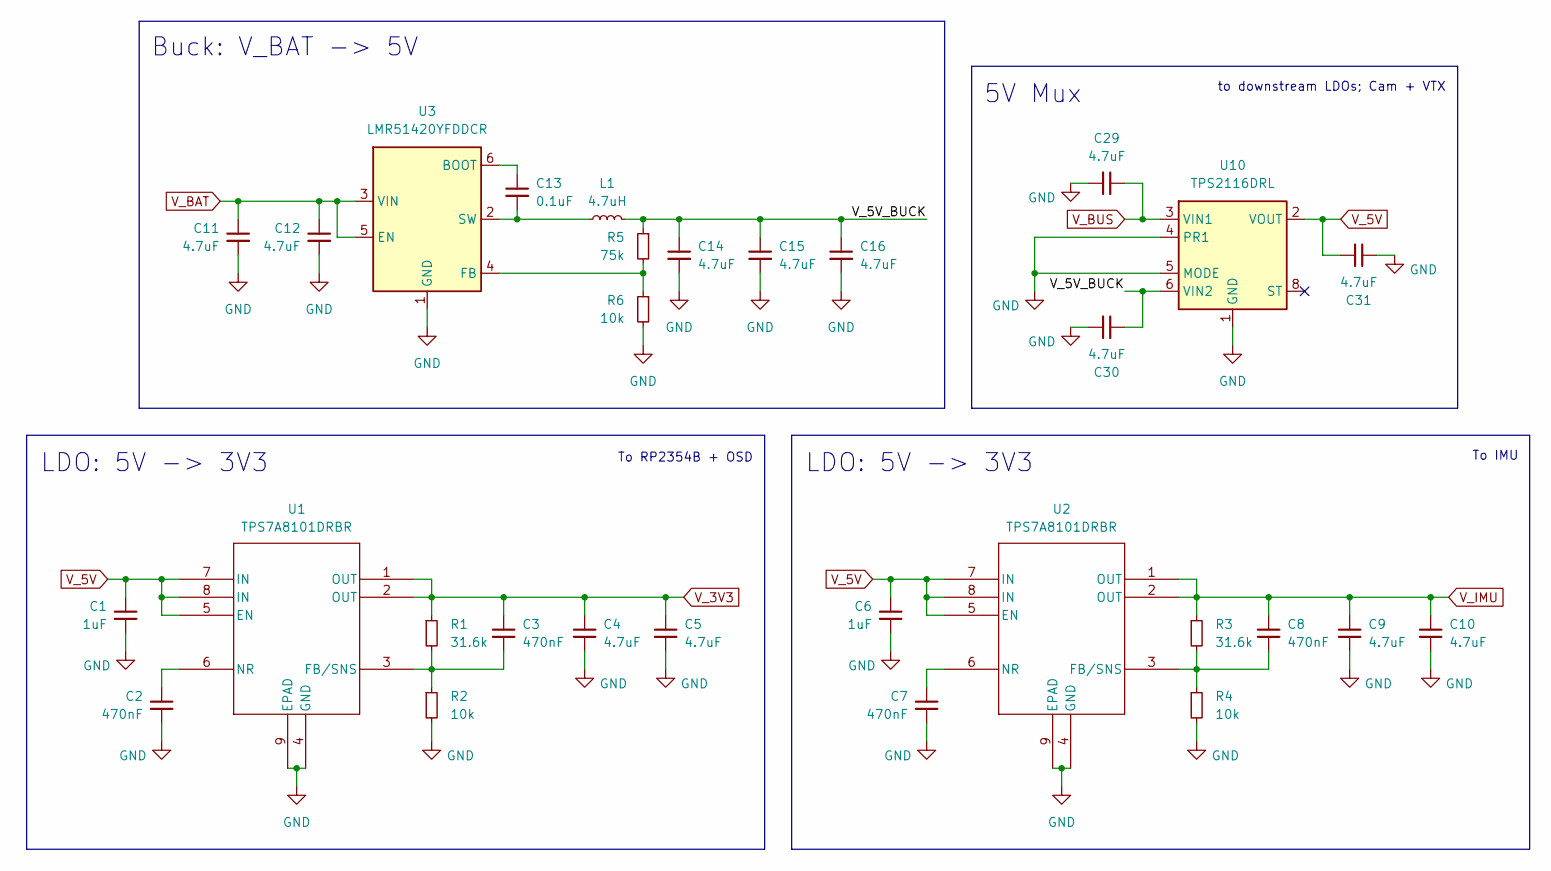
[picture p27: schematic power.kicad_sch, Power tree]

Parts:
C1, C6: 1uF; C_0402
C2, C3, C7, C8: 470nF; C_0402
C4, C5, C9, C10, C29, C30, C31: 4.7uF; C_0402
C11, C12: 4.7uF; C_0603_1608Metric; MPN CL10A475KL8NRNC; LCSC# C307467
C13: 0.1uF; C_0402; MPN CGA2B3X7R1V104KT0Y0F; LCSC# C343047
C14, C15, C16: 4.7uF; C_0402; MPN TDK105CBJ475MV-F; LCSC# C22385335
L1: 4.7uH; L_1210_3225Metric; MPN BCL322520RT-4R7M-D; LCSC# C3224690
R1, R3: 31.6k; R_0402
R2, R4: 10k; R_0402
R5: 75k; R_0402; MPN RC0402FR-07160KL; LCSC# C273334
R6: 10k; R_0402; MPN RC0402FR-0710KL; LCSC# C60490
U1, U2: TPS7A8101DRBR; MPN TPS7A8101DRBR; LCSC# C465730
U3: LMR51420YFDDCR; MPN LMR51420YFDDCR; LCSC# C7296200
U10: TPS2116DRL

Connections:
/Power/V_5V_BUCK: C14.1, C15.1, C16.1, C30.1, L1.2, R5.1, U10.6 (VIN2)
GND: C1.2, C2.2, C4.2, C5.2, C6.2, C7.2, C9.2, C10.2, C11.2, C12.2, C14.2, C15.2, C16.2, C29.2, C30.2, C31.2, R2.2, R4.2, R6.2, U1.4 (GND), U1.9 (EPAD), U2.4 (GND), U2.9 (EPAD), U3.1 (GND), U10.1 (GND), U10.4 (PR1), U10.5 (MODE); also elsewhere on the board
unnamed: C3.2, R1.2, R2.1, U1.3 (FB/SNS)
unnamed: C2.1, U1.6 (NR)
unnamed: C8.2, R3.2, R4.1, U2.3 (FB/SNS)
unnamed: C7.1, U2.6 (NR)
unnamed: C13.1, U3.6 (BOOT)
unnamed: R5.2, R6.1, U3.4 (FB)
unnamed: C13.2, L1.1, U3.2 (SW)
V_3V3: C3.1, C4.1, C5.1, R1.1, U1.1 (OUT), U1.2 (OUT); also elsewhere on the board
V_5V: C1.1, C6.1, C31.1, U1.5 (EN), U1.7 (IN), U1.8 (IN), U2.5 (EN), U2.7 (IN), U2.8 (IN), U10.2 (VOUT), U10.7 (VOUT); also elsewhere on the board
V_BAT: C11.1, C12.1, U3.3 (VIN), U3.5 (EN); also elsewhere on the board
V_BUS: C29.1, U10.3 (VIN1); also elsewhere on the board
V_IMU: C8.1, C9.1, C10.1, R3.1, U2.1 (OUT), U2.2 (OUT); also elsewhere on the board

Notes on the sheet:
To RP2354B + OSD
LDO: 5V -> 3V3
5V Mux
To IMU
Buck: V_BAT -> 5V
to downstream LDOs; Cam + VTX

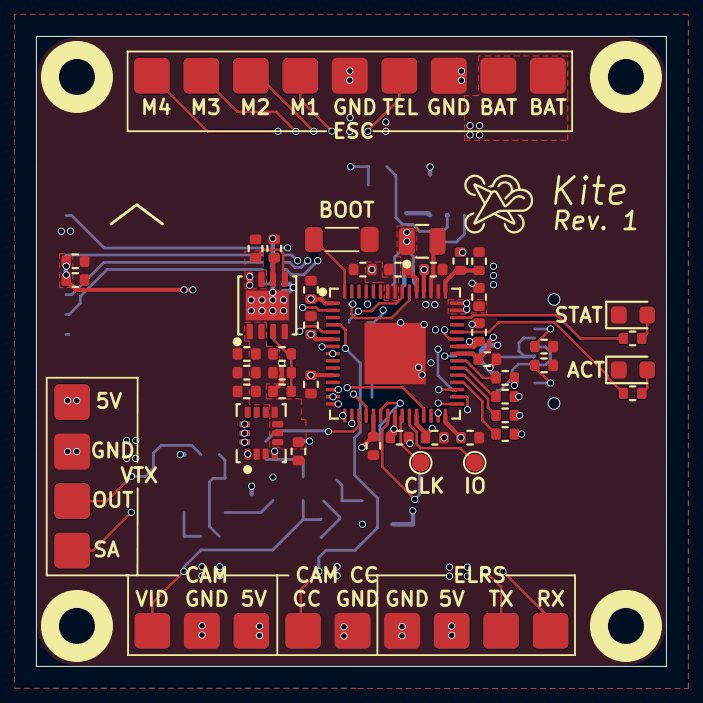
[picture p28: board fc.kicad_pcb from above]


Board: 6 copper layers, 35.0 x 35.0 mm, 103 parts (56 on the bottom side), 72 nets.

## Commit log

2026-08-04 h/init: initial commit
    [esc.csv, esc.kicad_pcb, esc.kicad_sch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]
2026-08-04 h/fix: add thermal vias for LDO
    [esc.kicad_pcb]
2026-08-19 h/fix: separate power into a separate sheet; send to fab
    [esc.kicad_pcb, esc.kicad_sch, power.kicad_sch]
2026-08-24 h/feat: preliminary rev 2 schematic
    [esc.csv, esc.kicad_pcb, esc.kicad_sch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]
2026-08-24 chore: prep: footprints, 3d models, pcb
    [esc.kicad_pcb, esc.kicad_sch, esc_module.kicad_sch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]
2026-08-25 h/feat: gate drive routing + prelim layout
    [esc.kicad_pcb, esc.kicad_sch, esc_module.kicad_sch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]
2026-08-26 h/fix: update schematic to better match AM32 hardware groups; further layout work
    [esc.kicad_pcb, esc_module.kicad_sch]
2026-08-26 h/feat: placement
    [esc.kicad_pcb]
2026-08-26 h/feat: layout - 1/4 motors
    [esc.kicad_pcb, esc_module.kicad_sch, power.kicad_sch]
2026-08-27 h/feat: layout
    [esc.kicad_pcb, power.kicad_sch]
2026-08-28 h/feat: power stage placement
    [esc.kicad_pcb, power.kicad_sch]
2026-08-28 h/fix: move v_bat sensing to FC
    [esc.kicad_pcb, esc.kicad_sch]
2026-08-28 h/fix: edge cuts
    [esc.kicad_pcb]
2026-08-28 h/feat: power stage
    [esc.kicad_pcb, esc_module.kicad_sch]
2026-08-30 h/feat: placement; power stage pending
    [esc.kicad_pcb, esc_module.kicad_sch, half_bridge.kicad_sch]
2026-08-31 h/feat: power stage; finalise placement
    [esc.kicad_pcb, esc.kicad_sch, power.kicad_sch]
2026-09-01 h/feat: 2/4 escs
    [esc.kicad_pcb]
2026-09-01 h/feat: finalise power stage
    [esc.kicad_pcb]
2026-09-02 h/feat: 3/4 escs
    [esc.kicad_pcb]
2026-09-03 h/feat: 4/4 escs
    [esc.kicad_pcb]
2026-09-03 h/fix: update ina180 footprint
    [esc.kicad_pcb]
2026-09-04 h/feat: global GND + VBAT pours, 2/4 phase + v_fet pours
    [esc.kicad_pcb]
2026-09-04 h/feat: top level + global pours
    [esc.kicad_pcb]
2026-09-04 h/fix: alignment; zone priority
    [esc.kicad_pcb]
2026-09-06 h/feat: add vias for central mlccs
    [esc.kicad_pcb, esc.kicad_sch]
2026-09-07 h/feat: rework power stage: power drv8300 from 10v; remove 5v FC passthrough
    [esc.kicad_pcb, esc.kicad_sch, esc_module.kicad_sch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]
2026-09-07 h/feat: add remaining vias; fix stubborn DRC errors
    [esc.kicad_pcb]
2026-09-07 h/feat: clean up connections and DRC violations
    [esc.kicad_pcb, power.kicad_sch]
2026-09-07 chore: nitpicky power trace
    [esc.kicad_pcb]
2026-09-07 h/fix: update FET name in schematic
    [half_bridge.kicad_sch]
2026-09-08 h/feat: silkscreen
    [esc.kicad_pcb]
2026-09-08 h/fix: add missing silkscreen
    [esc.kicad_pcb]
2026-09-08 h/fix: add polarity indicators
    [esc.kicad_pcb]
2026-09-08 h/feat: use hall sensor IC for current sensing instead of CSA; allocate another VBAT layer
    [esc.kicad_pcb, esc_module.kicad_sch]
2026-09-08 h/fix: add thermal vias for mcu
    [esc.kicad_pcb]
2026-09-09 h/feat: 2/4
    [esc.kicad_pcb]
2026-09-10 h/feat: 4/4; power stage routing
    [esc.kicad_pcb]
2026-09-10 h/feat: change stackup to better reflect JLCs physical stackup
    [esc.kicad_pcb]
2026-09-10 chore: add BOM
    [esc.csv, esc.kicad_sch, esc_module.kicad_sch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]
2026-09-13 chore: update PCB to reflect schem meta
    [esc.kicad_pcb]
2026-09-13 h: add final silkscreen; fab!
    [esc.kicad_pcb]
2026-09-17 fc: add power section to schematic
    [fc.kicad_pcb, fc.kicad_sch, power.kicad_sch]
2026-09-17 fc: add peripherals and sensors
    [fc.kicad_sch, peripherals.kicad_sch, power.kicad_sch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]
2026-09-17 fc: add 5V mux and OSD
    [fc.kicad_sch, osd.kicad_sch, peripherals.kicad_sch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]
2026-09-18 fc: update formatting; route RP2354 passives
    [fc.kicad_sch, osd.kicad_sch]
2026-09-18 fc: delete barometer; finalise schematic
    [fc.kicad_sch, peripherals.kicad_sch, power.kicad_sch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]
2026-09-19 fc: add footprints
    [fc.kicad_sch, osd.kicad_sch, peripherals.kicad_sch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]
2026-09-19 fc: fix peripherals
    [fc.kicad_sch, peripherals.kicad_sch, sensors.kicad_sch]
2026-09-19 fc: swap IMU to LSM6DSK320X
    [sensors.kicad_sch]
2026-09-20 fc: update schem to reflect ST datasheet
    [sensors.kicad_sch]
2026-09-20 fc: schematic tweaks; prelim power stage + connector layout
    [fc.kicad_pcb, fc.kicad_sch, osd.kicad_sch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]
2026-09-21 fc: prelim OSD layout
    [fc.kicad_pcb]
2026-09-21 fc: schematic footprint changes
    [fc.kicad_pcb, fc.kicad_sch, osd.kicad_sch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]
2026-09-21 fc: prelim MCU and IMU layout
    [fc.kicad_pcb, fc.kicad_sch]
2026-09-21 fc: prelim MCU + IMU
    [fc.kicad_pcb, fc.kicad_sch]
2026-09-22 fc: add power pours
    [fc.kicad_pcb, power.kicad_sch]
2026-09-22 fc: OSD
    [fc.kicad_pcb, osd.kicad_sch]
2026-09-22 fc: layout work
    [fc.kicad_pcb]
2026-09-22 fc: PDN; further layout work
    [fc.kicad_pcb, peripherals.kicad_sch]
2026-09-23 fc: fix PDB
    [fc.kicad_pcb]
2026-09-23 fc: routing and pours
    [fc.kicad_pcb, fc.kicad_sch, peripherals.kicad_sch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]
2026-09-23 fc: silkscreen
    [fc.kicad_pcb]
2026-09-23 fc: add pads; finishing touches
    [fc.kicad_pcb]
2026-09-23 fc: fill zones
    [fc.kicad_pcb]
2026-09-23 fc: add dshot resistors
    [fc.kicad_pcb, fc.kicad_sch]
2026-09-23 fc: footprints
    [fc.kicad_pcb, fc.kicad_sch, osd.kicad_sch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]
2026-09-24 fc: footprint changes
    [fc.kicad_pcb]
2026-09-24 fc: add solder paste opening to d_0402
    [fc.kicad_pcb]
2026-09-24 fc: add silkscreen to mounting holes
    [fc.kicad_pcb]
2026-09-25 fc: route osd_en on l3
    [fc.kicad_pcb]
2026-09-26 fc: clean up traces
    [fc.kicad_pcb]
2026-09-30 h: leds
    [esc.kicad_sch]
2026-10-04 fc: add LEDs
    [fc.kicad_pcb, fc.kicad_sch]
2026-10-09 esc: rev 3, mainly visual changes
    [esc.kicad_pcb, esc.kicad_sch]
2026-10-11 h: move dshot traces to L5
2026-10-13 h: update FET footprint
2026-10-13 h: add clearance to SHA traces, schematic formatting
2026-10-13 h: update BOM and FET for 5S
2026-10-24 general: update ESC schem and README
2026-10-24 fc: add rbleed, swap comparator, clamp video to vref
2026-10-24 fc: move DC restoration/clamp to shared path
2026-10-24 fc: edit values to add temperature drift robustness to OSD
2026-10-24 fc: final resistor edit
2026-11-11 fc/h: replot esc; remove CC from fc; hiatus for finals
2026-11-11 fc: add 10k resistor between qspi_ss and gnd
